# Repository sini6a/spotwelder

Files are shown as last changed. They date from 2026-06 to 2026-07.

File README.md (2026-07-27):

# Open Source Spot Welder

An easy-to-assemble, through-hole spot welder capable of switching high currents for welding nickel strip to lithium-ion cells. Controlled by an ATtiny13 microcontroller.

The welder is powered by a 12 V car battery or another suitable high-current battery source. The PCB, schematic, firmware, enclosure, and fabrication files are included in this repository.

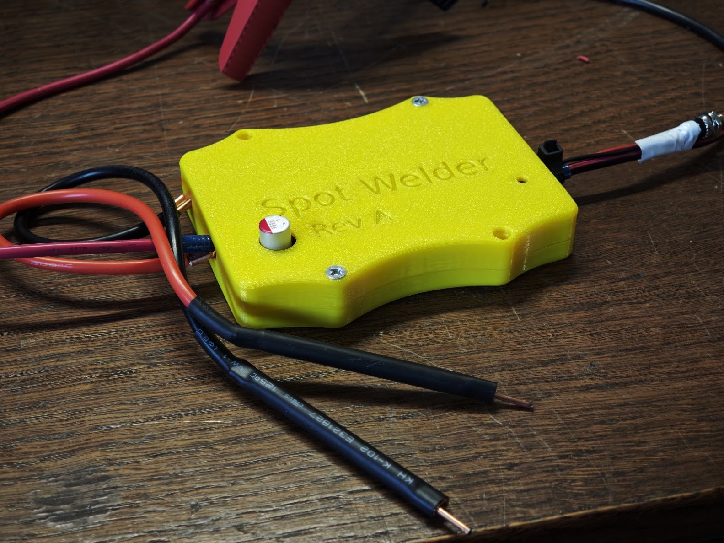
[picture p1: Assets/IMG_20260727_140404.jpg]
Board Assembly

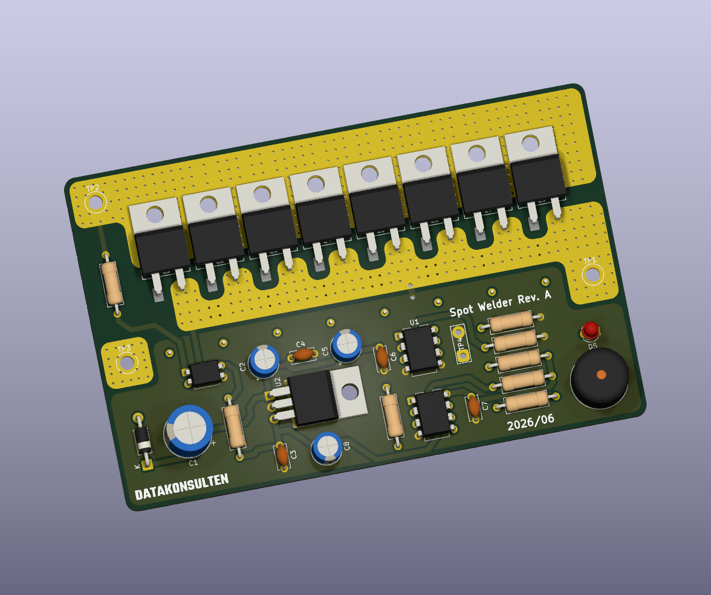
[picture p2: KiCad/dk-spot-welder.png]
Board render


> [!WARNING]
> This project switches extremely high current from a battery. Incorrect wiring, insufficient conductors, short circuits, or excessive pulse duration can cause fire, burns, damaged cells, destroyed MOSFETs, or battery failure.

## Sponsor

PCB fabrication for this project was sponsored by [PCBWay](https://www.pcbway.com/).

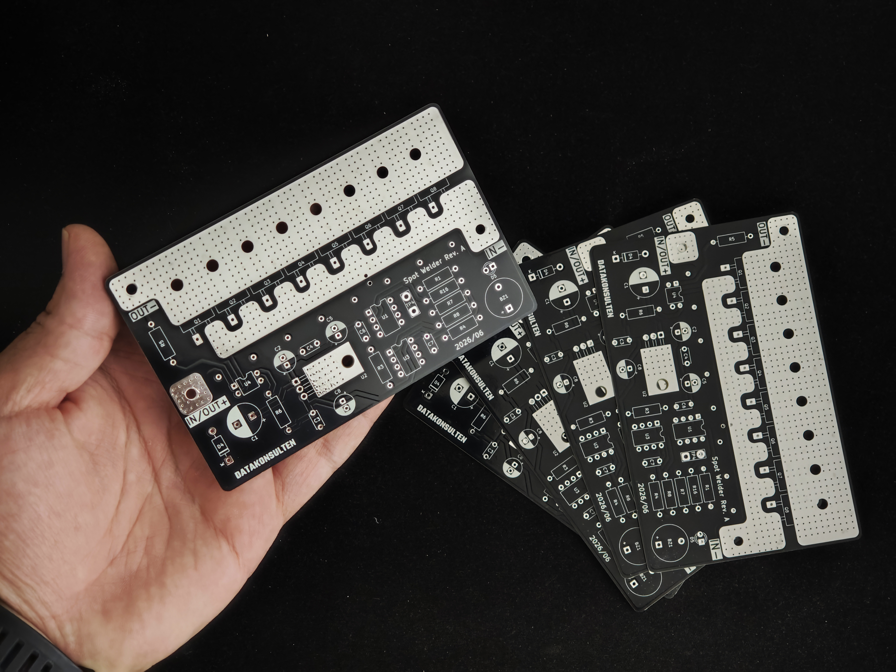
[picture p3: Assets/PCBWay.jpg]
PCBWay PCBs


## Features

* **Eight-MOSFET switching bank**
  Eight IRF1404 N-channel MOSFETs are connected in parallel to switch the welding current. Each MOSFET has an individual 10 Ω gate resistor to help control switching and reduce gate ringing.

* **Dedicated MOSFET gate driver**
  An MCP1407 drives all eight MOSFET gates simultaneously. A hardware pull-down resistor on the driver input keeps the MOSFET bank off while the microcontroller is starting, resetting, or unpowered.

* **Automatic touch-to-weld triggering**
  A PC817 optocoupler-based sensing circuit detects when both welding probes are in contact with a conductive workpiece. The isolated output signals the ATtiny13 to begin the welding sequence.

* **Adjustable 1–10 ms main pulse**
  A pushbutton connected to TP4 cycles the main weld-pulse duration from 1 to 10 ms.

* **EEPROM setting storage**
  The selected weld duration is saved in the ATtiny13 EEPROM and restored after the welder is disconnected from power.

* **LED and buzzer feedback**
  The onboard LED and passive piezo buzzer provide startup, welding, and setting-change feedback. When the duration is changed, the LED flashes and the buzzer beeps once for each selected millisecond.

* **Optional double-pulse welding**
  The firmware can produce a short pre-pulse followed by the adjustable main pulse. The pre-pulse can help settle the probe contact before the main weld.

* **Separated control and power grounds**
  The high-current welding ground (`GND`) and logic ground (`CTRL_GND`) are routed separately and joined at a single net-tie point to reduce switching noise at the microcontroller.

* **Reverse-polarity protection**
  A 1N5819 Schottky diode protects the 5 V control supply if the battery input is accidentally connected with reversed polarity.

* **Transient suppression**
  Four 5.0SMDJ14A TVS diodes help clamp voltage transients generated by the welding cables and other parasitic inductance when the MOSFET bank switches off.

* **Large high-current connection pads**
  The battery and welding connections use large exposed copper pads intended for soldered or mechanically secured high-current conductors.

* **Four-layer PCB**
  Copper zones on F.Cu, In1.Cu, In2.Cu, and B.Cu help distribute the short welding-current pulses through the MOSFET bank.

> [!IMPORTANT]
> PCB copper alone should not be treated as a complete high-current busbar. Thick copper cable, copper braid, copper strip, or another suitable reinforcement is recommended for the main battery and electrode current paths.

## How it works

1. **Power input**
   A 12 V car battery or another suitable high-current battery source is connected to the `IN/OUT+` and `IN-` pads.

2. **Probe contact detection**
   When both welding probes contact the conductive workpiece, the PC817 sensing circuit produces an isolated trigger signal for the ATtiny13.

3. **Trigger validation**
   The firmware verifies that the contact signal remains active for the configured debounce period.

4. **Pre-pulse**
   When double-pulse mode is enabled, the ATtiny13 briefly activates the MCP1407 and MOSFET bank for the configured pre-pulse duration.

5. **Pulse gap**
   The MOSFETs switch off for a short interval before the main pulse.

6. **Main weld pulse**
   The MOSFET bank switches on for the selected duration between 1 and 10 ms, passing a short burst of high current through the nickel strip and cell connection.

7. **Feedback and cooldown**
   The buzzer and LED confirm that the weld sequence completed. The firmware then enforces a cooldown period and waits for the probes to be lifted before another weld can begin.

## Weld-time adjustment

TP4 is used to change the main weld-pulse duration.

Each complete button press advances the setting by 1 ms:

```text
1 → 2 → 3 → 4 → 5 → 6 → 7 → 8 → 9 → 10 → 1 ms
```

After the value changes:

* The setting is saved to EEPROM.
* The LED flashes once per selected millisecond.
* The buzzer beeps at the same time as each flash.

For example, a 6 ms setting produces six LED flashes and six beeps.

The displayed value represents the **main pulse only**. When double-pulse mode is enabled, the fixed pre-pulse is added separately.

## Firmware

The firmware is located at:

```text
Firmware/main.c
```

It directly controls:

* The MCP1407 gate-driver input
* The PC817 automatic weld trigger
* The TP4 settings button
* The status LED
* The passive piezo buzzer
* EEPROM storage for the selected duration

The firmware forces the MOSFET-driver control pin low during startup. This works together with the hardware pull-down resistor on the MCP1407 input to reduce the risk of an unintended weld pulse during reset or power-up.

### Default configuration

| Definition | Default | Description |
| --- | ---: | --- |
| `WELD_PULSE_MIN_MS` | 1 ms | Lowest selectable main-pulse duration |
| `WELD_PULSE_MAX_MS` | 10 ms | Highest selectable main-pulse duration |
| `WELD_PULSE_DEFAULT_MS` | 6 ms | Used when EEPROM does not contain a valid setting |
| `USE_DOUBLE_PULSE` | 1 | Enables the pre-pulse and main-pulse sequence |
| `PRE_PULSE_MS` | 3 ms | Fixed pre-pulse duration |
| `PULSE_GAP_MS` | 80 ms | Delay between the pre-pulse and main pulse |
| `WELD_COOLDOWN_MS` |  800 ms | Minimum delay after a weld before re-arming |
| `TRIGGER_DEBOUNCE_MS` | 15 ms | Probe-contact validation time |
| `REQUIRE_TRIGGER_RELEASE` | 1 | Requires the probes to be lifted before another weld |
| `BEEP_ON_WELD_MS` | 60 ms | Weld-confirmation tone duration |
| `BUZZER_ACTIVE_TYPE` | 0 | Configures BZ1 as an externally driven passive piezo |
| `BUZZER_TONE_HZ` | 4000 Hz | Normal feedback-tone frequency |

Review the values in `Firmware/main.c` before flashing, as development versions may use different pre-pulse and timing defaults.

### Building and flashing

The firmware is built with AVR-GCC and optimized for the ATtiny13's limited 1 KB program memory.

```bash
cd Firmware

make
make flash
make fuses
```

The default Makefile targets are:

| Command | Action |
| --- | --- |
| `make` | Build the firmware and generate the HEX file |
| `make flash` | Flash the firmware over ISP |
| `make fuses` | Configure the 9.6 MHz internal oscillator with the divide-by-8 fuse, resulting in a 1.2 MHz CPU clock |

The default programmer configuration may need to be changed in the Makefile when using an Arduino as ISP instead of a USBasp.

## Enclosure

A two-piece enclosure is included and was designed in FreeCAD. 3xM4 Nuts should be installed while printing the enclosure.

| Assembled | Top and bottom |
| --- | --- |
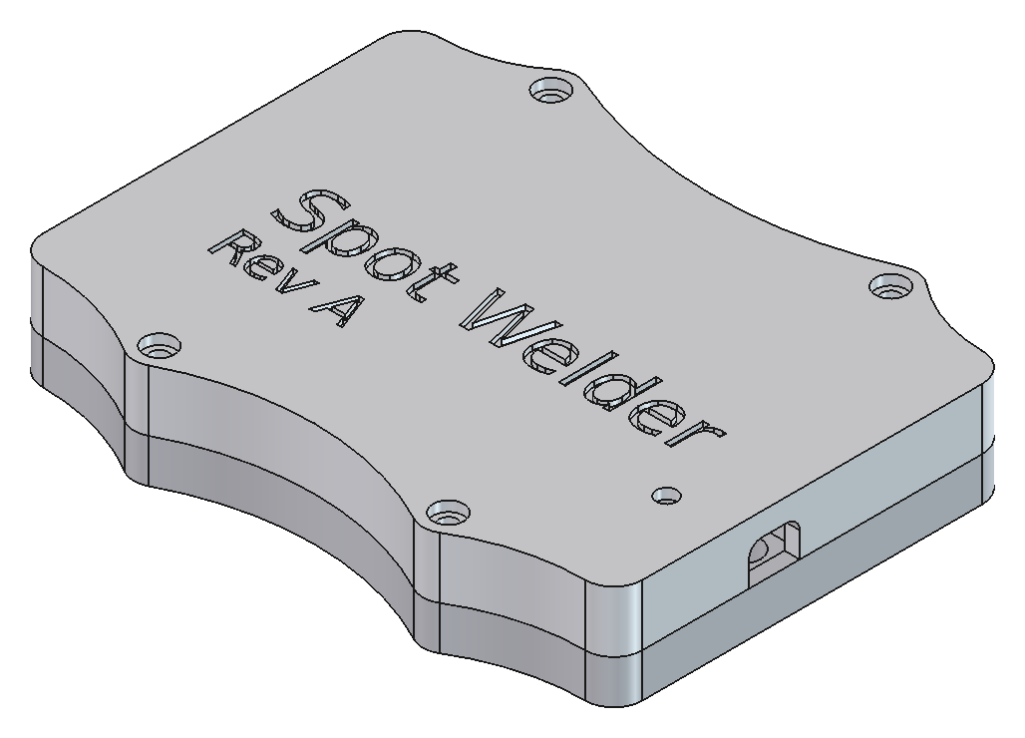
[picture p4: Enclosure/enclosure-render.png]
Enclosure render
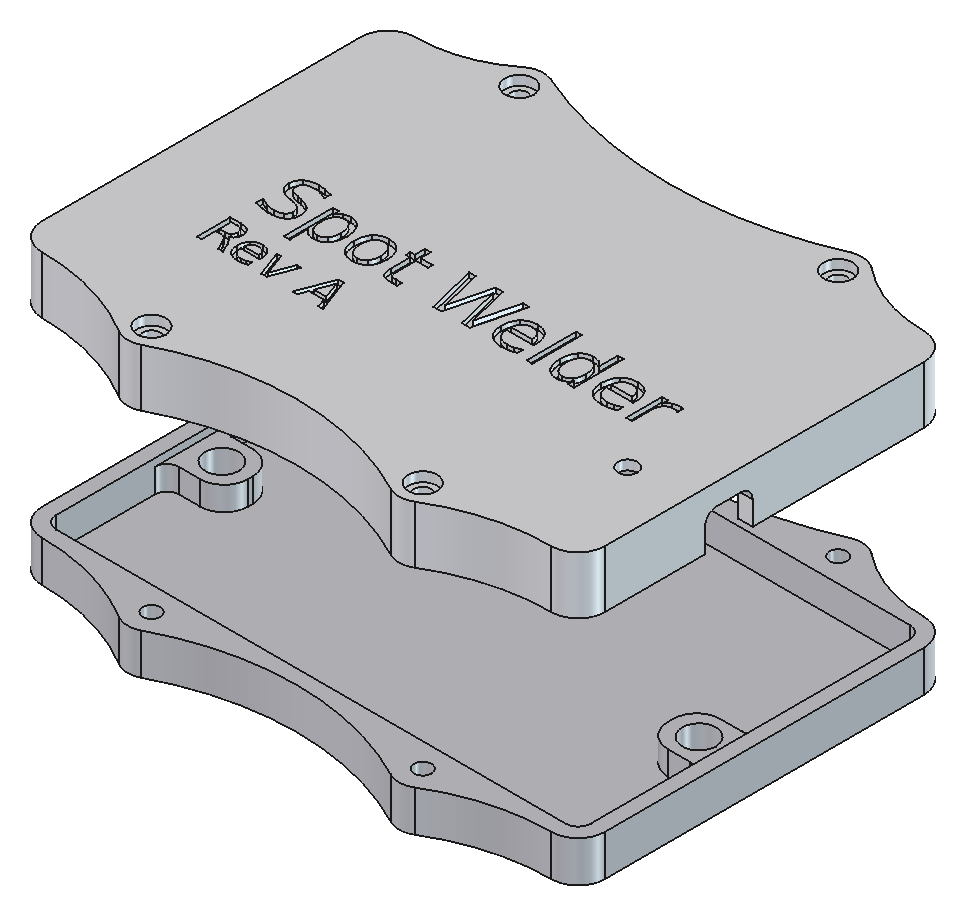
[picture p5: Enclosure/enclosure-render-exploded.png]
Exploded enclosure render
|  |  |

The enclosure includes:

* Four mounting bosses
* Screw-together top and bottom sections
* Side openings for the battery and electrode cables
* Source files for modification and 3D printing

Included files:

```text
Enclosure/SpotWelder.FCStd
Enclosure/Top Body.step
Enclosure/Bottom Body.step
```

## Project status

The Rev A hardware has been assembled, powered, and successfully used for spot welding.

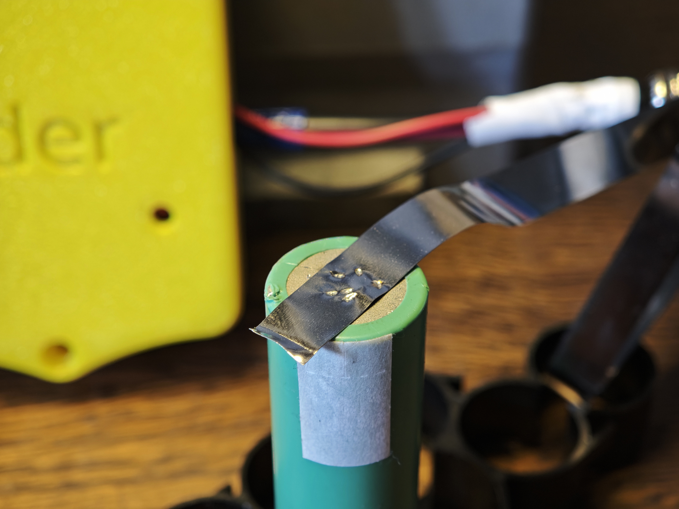
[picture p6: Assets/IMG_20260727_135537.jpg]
Battery weld


The following core functions have been tested:

* ATtiny13 startup
* MOSFET gate-driver control
* Automatic probe-contact triggering
* Timed welding pulses
* LED feedback
* Passive buzzer feedback
* Welding from a 12 V car battery

## License

This project is licensed under the **Creative Commons Attribution-NonCommercial-ShareAlike 4.0 International license**.

See [LICENCE.md](LICENCE.md) for the complete terms.

You may build, modify, and share the design for personal and non-commercial use, provided that attribution is retained and derivative works use the same license.

Commercial production or resale of boards based on this design requires permission from Datakonsulten Sverige AB.

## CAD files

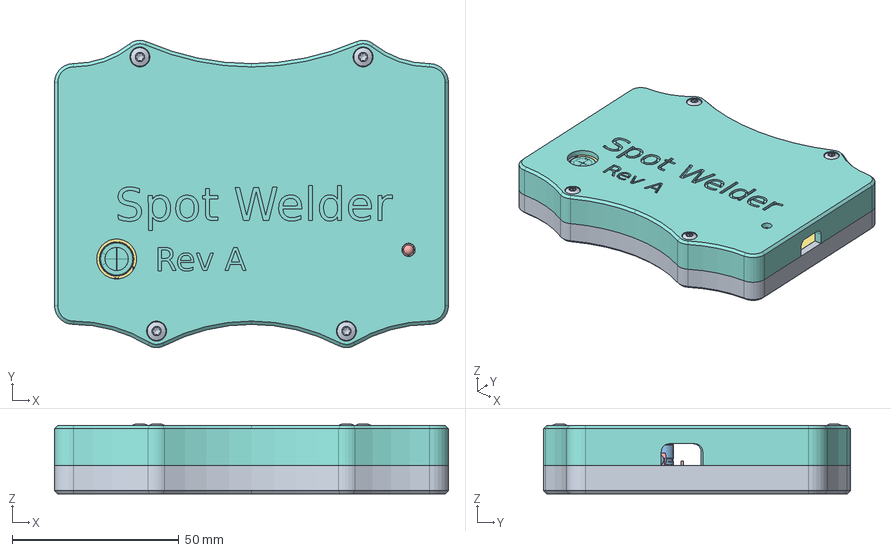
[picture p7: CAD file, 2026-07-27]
Enclosure/SpotWelder.FCStd
118.3 x 92.3 x 21.0 mm
Bottom Body
M4-Nut x 3
R_Axial_DIN0309_L90mm_D32mm_P1270mm_Horizontal
R_Axial_DIN0309_L90mm_D32mm_P1270mm_Horizontal001
LED_D3.0mm
C_Disc_D50mm_W25mm_P500mm
TO-220-2_Horizontal_TabDown
CP_Radial_D100mm_P500mm
TO-220-2_Horizontal_TabDown002
DIP-8_W7.62mm
CP_Radial_D63mm_P250mm
TO-220-2_Horizontal_TabDown004
TO-220-3_Horizontal_TabDown
TO-220-2_Horizontal_TabDown006
TO-220-2_Horizontal_TabDown008
TO-220-2_Horizontal_TabDown010
TO-220-2_Horizontal_TabDown012
CP_Radial_D63mm_P250mm001
R_Axial_DIN0309_L90mm_D32mm_P1270mm_Horizontal002
R_Axial_DIN0309_L90mm_D32mm_P1270mm_Horizontal003
Buzzer_12x95RM76
R_Axial_DIN0309_L90mm_D32mm_P1270mm_Horizontal004
C_Disc_D50mm_W25mm_P500mm001
R_Axial_DIN0309_L90mm_D32mm_P1270mm_Horizontal005
R_Axial_DIN0309_L90mm_D32mm_P1270mm_Horizontal006
C_Disc_D50mm_W25mm_P500mm002
C_Disc_D50mm_W25mm_P500mm003
D_DO-41_SOD81_P10.16mm_Horizontal
DIP-8_W7.62mm002
CP_Radial_D63mm_P250mm002
TO-220-2_Horizontal_TabDown014
DIP-4_W7.62mm
R_Axial_DIN0309_L90mm_D32mm_P1270mm_Horizontal007
D_SMC
R_Axial_DIN0309_L90mm_D32mm_P1270mm_Horizontal008
D_SMC002
R_Axial_DIN0309_L90mm_D32mm_P1270mm_Horizontal009
R_Axial_DIN0309_L90mm_D32mm_P1270mm_Horizontal010
R_Axial_DIN0309_L90mm_D32mm_P1270mm_Horizontal011
R_Axial_DIN0309_L90mm_D32mm_P1270mm_Horizontal012
R_Axial_DIN0309_L90mm_D32mm_P1270mm_Horizontal013
D_SMC004
R_Axial_DIN0309_L90mm_D32mm_P1270mm_Horizontal014
D_SMC006
R_Axial_DIN0309_L90mm_D32mm_P1270mm_Horizontal015
dk-spot-welder_silkscreen
dk-spot-welder_silkscreen001
dk-spot-welder_silkscreen002
dk-spot-welder_silkscreen003
dk-spot-welder_silkscreen004
dk-spot-welder_silkscreen005
dk-spot-welder_silkscreen006
dk-spot-welder_silkscreen007
dk-spot-welder_silkscreen008
dk-spot-welder_silkscreen009
dk-spot-welder_silkscreen010
dk-spot-welder_silkscreen011
dk-spot-welder_silkscreen012
dk-spot-welder_silkscreen013
dk-spot-welder_silkscreen014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

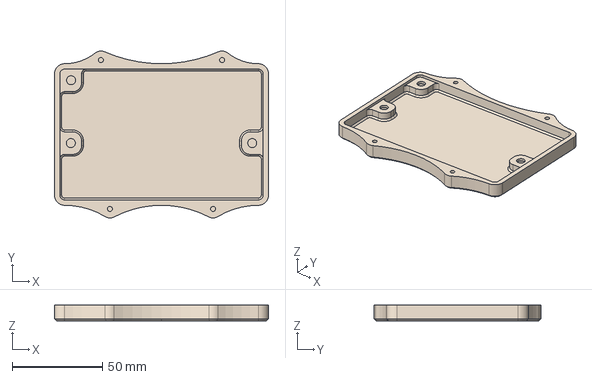
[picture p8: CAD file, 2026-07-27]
Enclosure/Bottom Body.step
118.3 x 92.3 x 8.60 mm

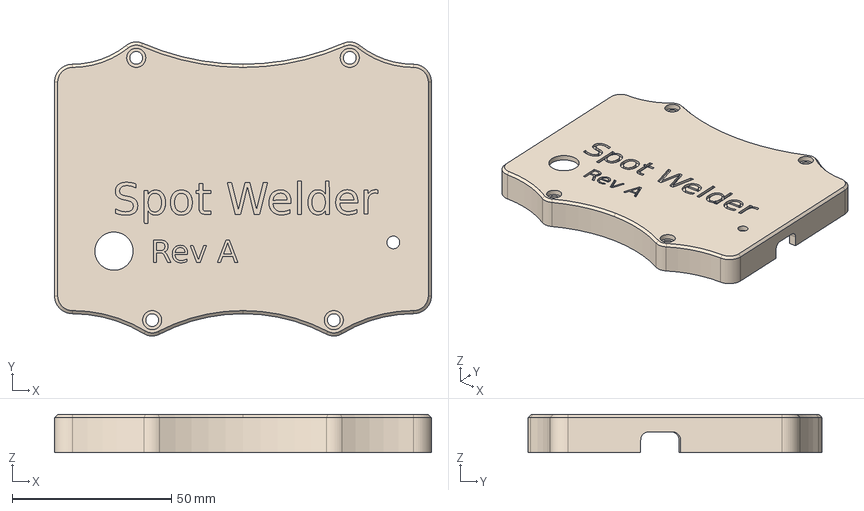
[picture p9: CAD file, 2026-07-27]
Enclosure/Top Body.step
118.3 x 92.3 x 12.0 mm

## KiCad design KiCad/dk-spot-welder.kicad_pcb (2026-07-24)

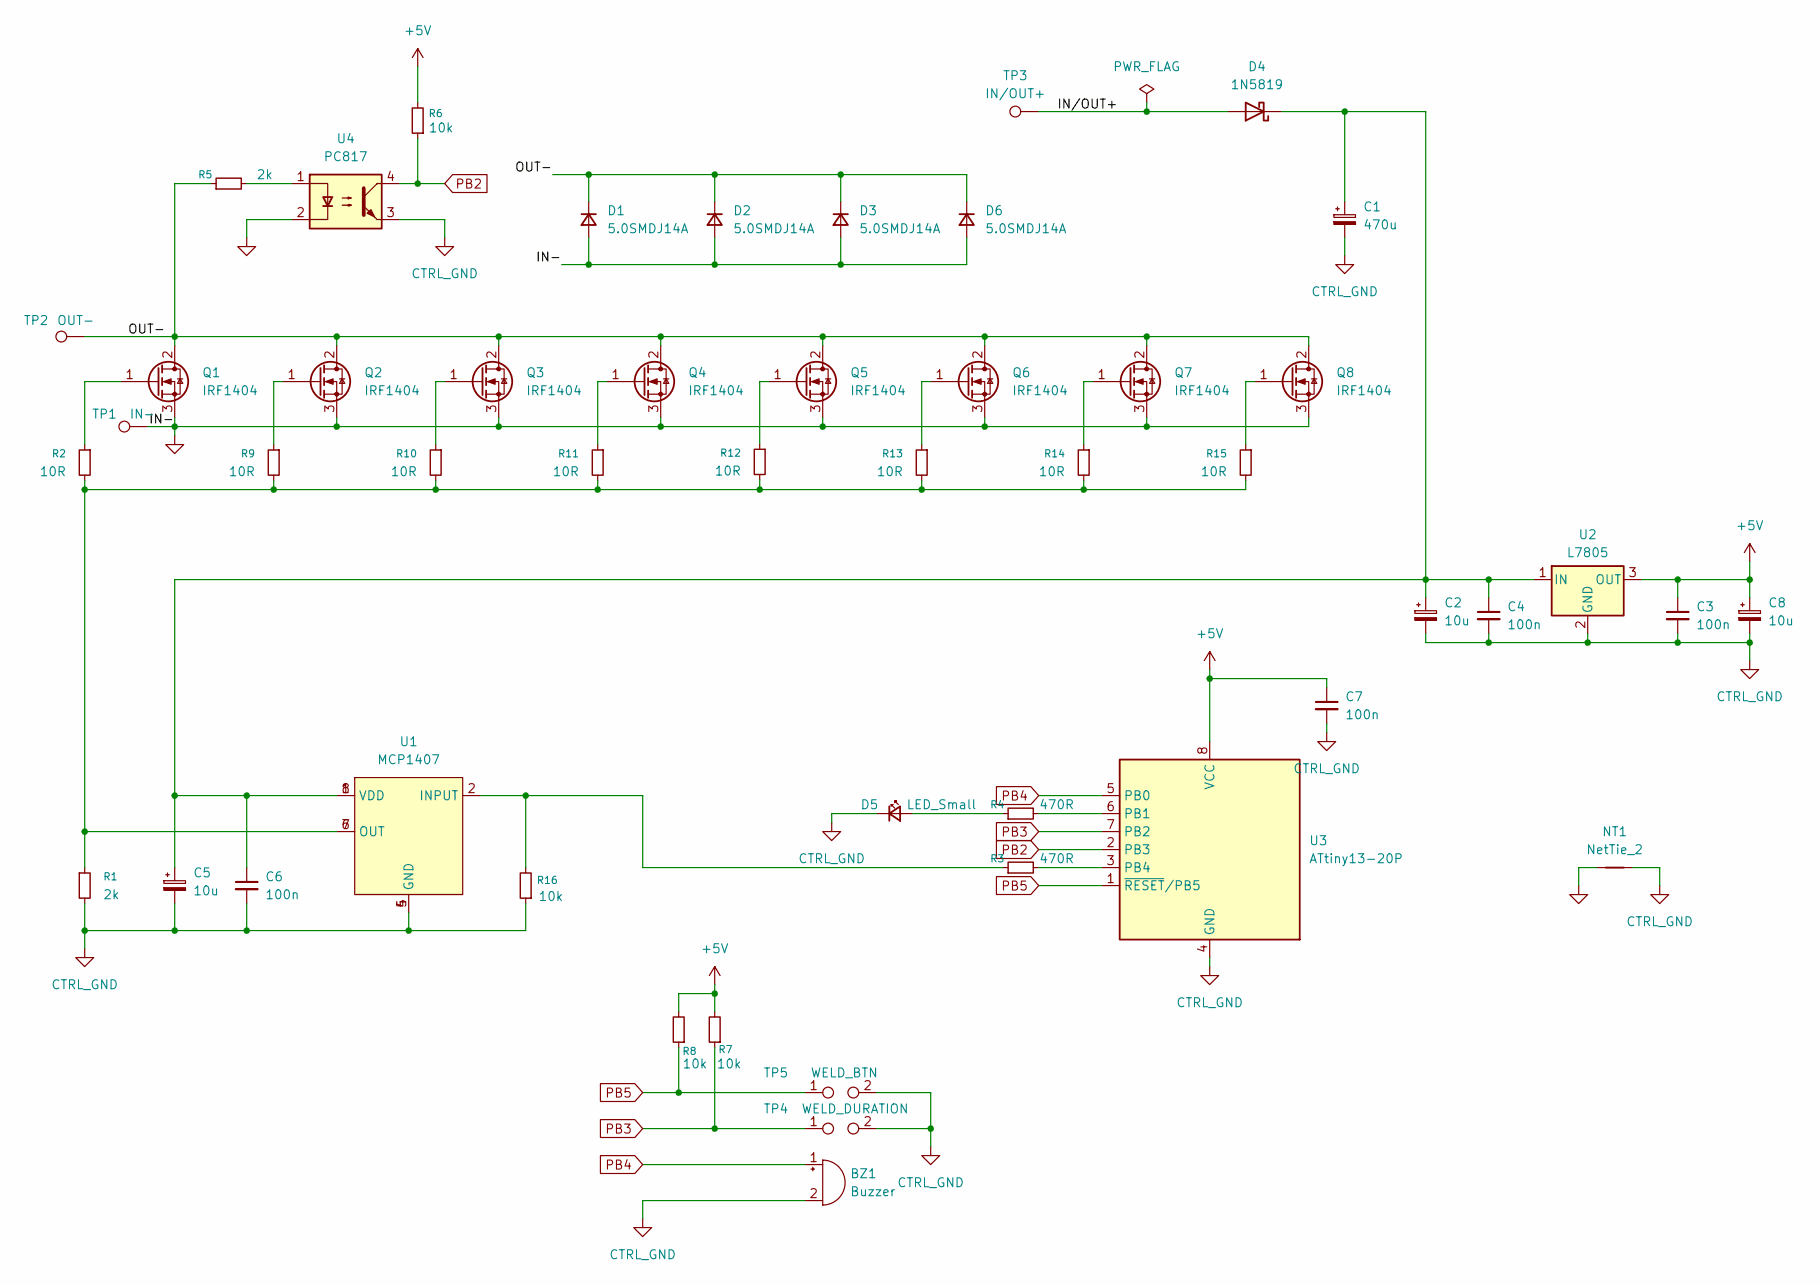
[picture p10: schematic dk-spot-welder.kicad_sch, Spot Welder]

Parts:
BZ1: Buzzer; Buzzer_12x9.5RM7.6
C1: 470u; CP_Radial_D10.0mm_P5.00mm
C2, C5, C8: 10u; CP_Radial_D6.3mm_P2.50mm
C3, C4, C6, C7: 100n; C_Disc_D5.0mm_W2.5mm_P5.00mm
D1, D2, D3, D6: 5.0SMDJ14A; D_SMC_Handsoldering
D4: 1N5819; D_DO-41_SOD81_P10.16mm_Horizontal
D5: LED_Small; LED_D3.0mm
NT1: NetTie_2; NetTie-2_THT_Pad1.0mm
Q1, Q2, Q3, Q4, Q5, Q6, Q7, Q8: IRF1404; TO-220-2_Horizontal_TabDown
R1, R5: 2k; R_Axial_DIN0309_L9.0mm_D3.2mm_P12.70mm_Horizontal
R2, R9, R10, R11, R12, R13, R14, R15: 10R; R_Axial_DIN0309_L9.0mm_D3.2mm_P12.70mm_Horizontal
R3, R4: 470R; R_Axial_DIN0309_L9.0mm_D3.2mm_P12.70mm_Horizontal
R6, R7, R8, R16: 10k; R_Axial_DIN0309_L9.0mm_D3.2mm_P12.70mm_Horizontal
TP1: IN-; MountingHole_4mm_Pad_Via
TP2: OUT-; MountingHole_4mm_Pad_Via
TP3: IN/OUT+; MountingHole_4mm_Pad_Via
TP4: WELD_DURATION; TestPoint_2Pads_Pitch5.08mm_Drill1.3mm
TP5: WELD_BTN; TestPoint_2Pads_Pitch5.08mm_Drill1.3mm
U1: MCP1407; DIP-8_W7.62mm
U2: L7805; TO-220-3_Horizontal_TabDown
U3: ATtiny13-20P; DIP-8_W7.62mm
U4: PC817; DIP-4_W7.62mm

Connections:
+5V: C3.1, C7.1, C8.1, R6.2, R7.2, R8.2, U2.3 (OUT), U3.8 (VCC)
/IN/OUT+: D4.2 (A), TP3.1 (1_1)
/OUT-: D1.1 (K), D2.1 (K), D3.1 (K), D6.1 (K), Q1.2 (D), Q2.2 (D), Q3.2 (D), Q4.2 (D), Q5.2 (D), Q6.2 (D), Q7.2 (D), Q8.2 (D), R5.1, TP2.1 (1_1)
CTRL_GND: BZ1.2 (-), C1.2, C2.2, C3.2, C4.2, C5.2, C6.2, C7.2, C8.2, D5.1 (K), NT1.2, R1.2, R16.1, TP4.2, TP5.2, U1.4 (GND), U1.5 (GND), U2.2 (GND), U3.4 (GND), U4.3
GND: D1.2 (A), D2.2 (A), D3.2 (A), D6.2 (A), NT1.1, Q1.3 (S), Q2.3 (S), Q3.3 (S), Q4.3 (S), Q5.3 (S), Q6.3 (S), Q7.3 (S), Q8.3 (S), TP1.1 (1_1), U4.2
unnamed: C1.1, C2.1, C4.1, C5.1, C6.1, D4.1 (K), U1.1 (VDD), U1.8 (VDD), U2.1 (IN)
unnamed: D5.2 (A), R4.1
unnamed: Q1.1 (G), R2.1
unnamed: Q2.1 (G), R9.1
unnamed: Q3.1 (G), R10.1
unnamed: Q4.1 (G), R11.1
unnamed: Q5.1 (G), R12.1
unnamed: Q6.1 (G), R13.1
unnamed: Q7.1 (G), R14.1
unnamed: Q8.1 (G), R15.1
unnamed: R1.1, R2.2, R9.2, R10.2, R11.2, R12.2, R13.2, R14.2, R15.2, U1.6 (OUT), U1.7 (OUT)
unnamed: R5.2, U4.1
unnamed: R3.1, R16.2, U1.2 (INPUT)
unnamed: R4.2, U3.6 (PB1)
unnamed: R3.2, U3.3 (PB4)
PB2: R6.1, U3.2 (PB3), U4.4
PB3: R7.1, TP4.1, U3.7 (PB2)
PB4: BZ1.1 (+), U3.5 (PB0)
PB5: R8.1, TP5.1, U3.1 (~RESET/PB5)

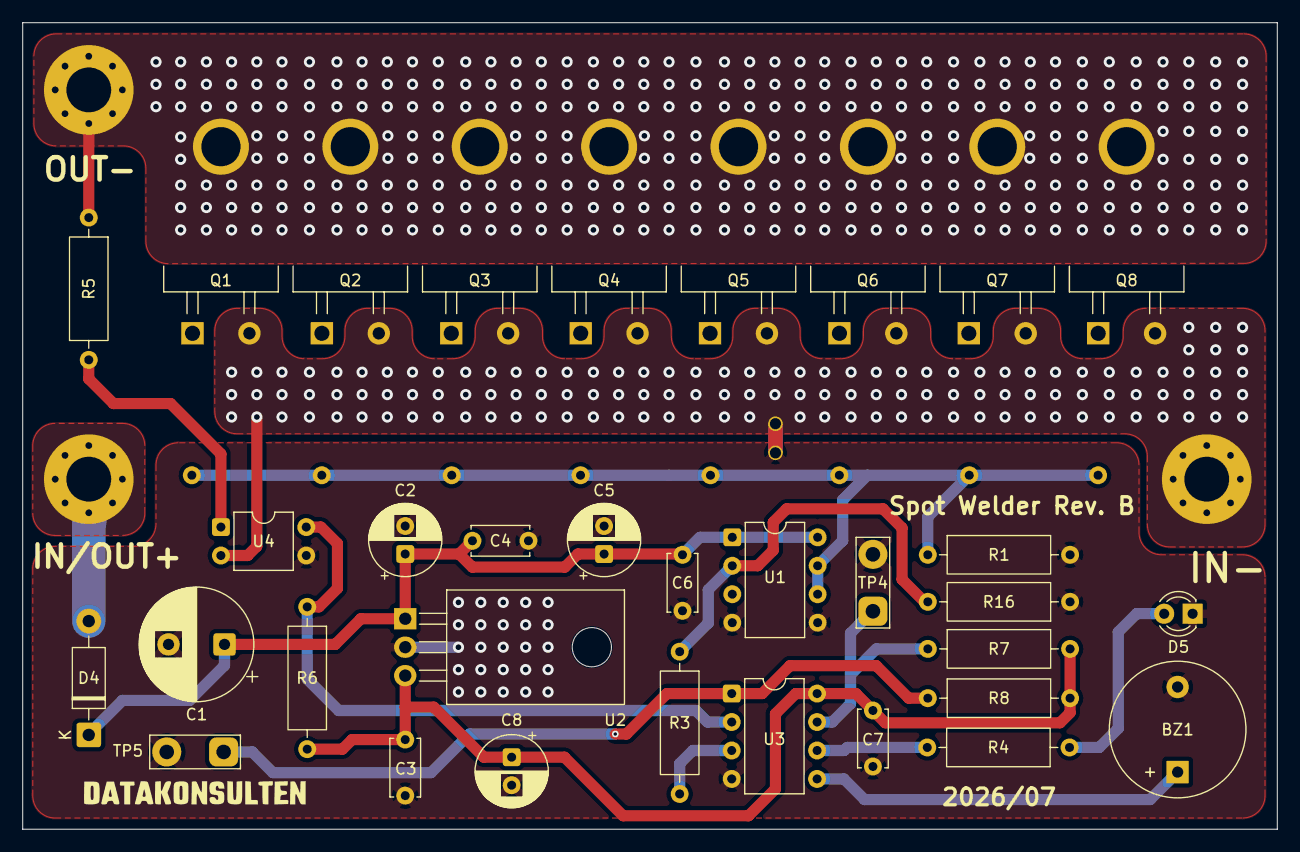
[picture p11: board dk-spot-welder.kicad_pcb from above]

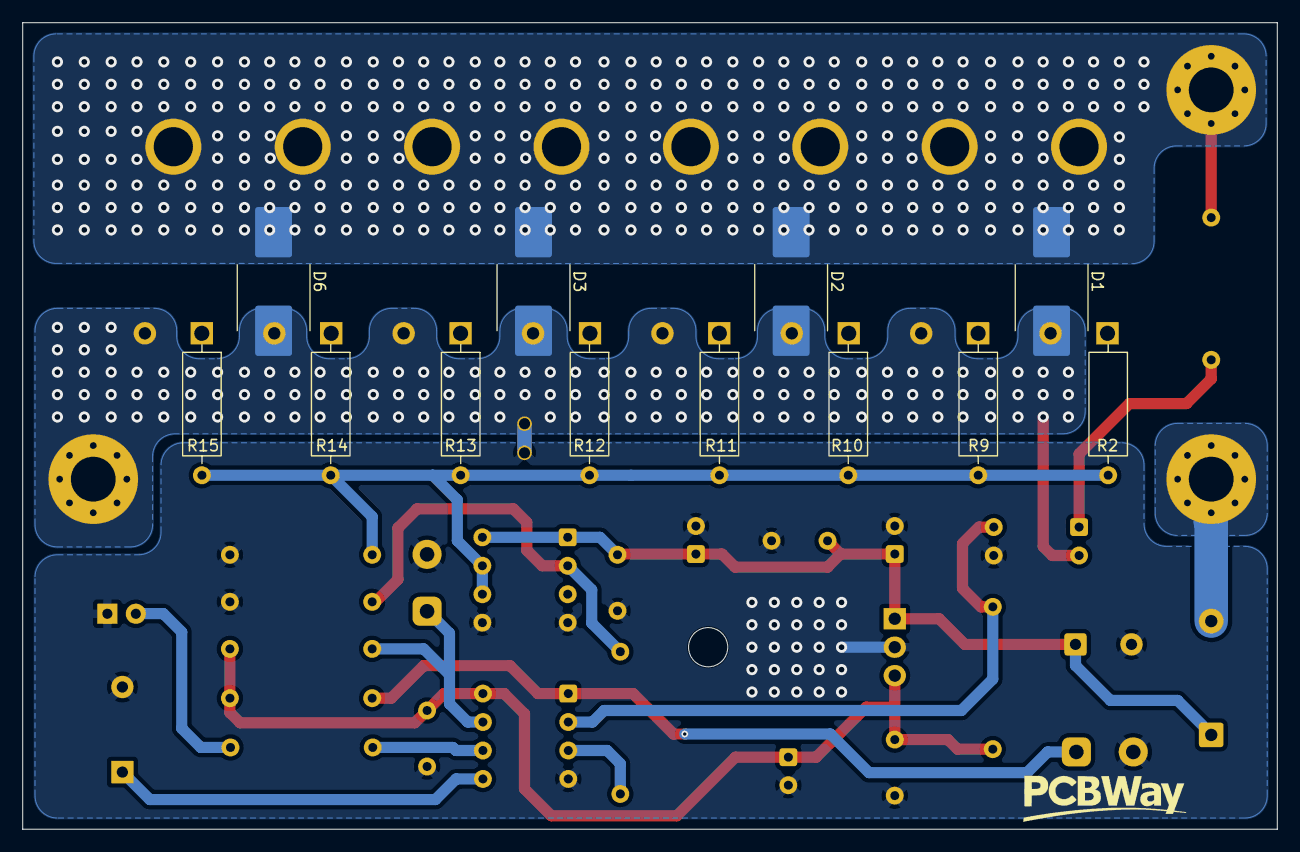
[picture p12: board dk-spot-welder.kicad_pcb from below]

Board: 4 copper layers, 112.0 x 72.0 mm, 49 parts (12 on the bottom side), 24 nets.

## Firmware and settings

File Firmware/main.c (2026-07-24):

/*
 * Datakonsulten Spot Welder - ATtiny13-20P firmware
 *
 * Pin mapping (derived from KiCad/dk-spot-welder.kicad_sch, U3):
 *   PB0 (pin 5) -> BZ1   buzzer, active HIGH, no series resistor (active/self-oscillating
 *                  piezo buzzer assumed - see BUZZER_ACTIVE_TYPE below)
 *   PB1 (pin 6) -> D5    status LED via R4, active HIGH
 *   PB2 (pin 7) -> TP4   manual trigger button header, external pull-up R7 to +5V,
 *                  active LOW (button pulls to CTRL_GND when pressed)
 *   PB3 (pin 2) -> U4    PC817 phototransistor output, external pull-up R6 to +5V,
 *                  active LOW (opto conducts when welding tips touch the workpiece)
 *   PB4 (pin 3) -> R3 -> U1 MCP1407 INPUT, active HIGH = MOSFET bank ON (welding current
 *                  flowing). R16 hardware-pulls this net low at the driver input as a
 *                  fail-safe, but firmware also forces PB4 low before anything else runs.
 *   PB5 (pin 1) -> RESET, pulled up by R8. Not used as GPIO.
 *
 * All user-tunable parameters are grouped at the top of this file.
 */

#define F_CPU 1200000UL   /* ATtiny13 factory-default fuses = 9.6MHz internal RC / 8 = 1.2MHz.
                              Must match the fuses actually programmed into the chip - see
                              Makefile `fuses` / `fuses-fast` targets. */

#include <avr/io.h>
#include <avr/eeprom.h>
#include <util/delay.h>

/* ===================== USER CONFIGURATION ===================== */

/* --- Weld pulse timing (milliseconds) --- */
#define WELD_PULSE_MIN_MS       1   /* Lowest selectable main-pulse duration */
#define WELD_PULSE_MAX_MS      10   /* Highest selectable main-pulse duration */
#define WELD_PULSE_DEFAULT_MS  5   /* Used when EEPROM contains an invalid value */

#define SETTINGS_BUTTON_MS      30   /* TP4 press and release debounce time */
#define SETTING_BLINK_ON_MS     80   /* LED-on time for each indication blink */
#define SETTING_BLINK_OFF_MS   120   /* LED-off time between indication blinks */
#define USE_DOUBLE_PULSE         1   /* 1 = fire a short pre-pulse before the main pulse,
                                         0 = single pulse only */
#define PRE_PULSE_MS              1   /* Pre-pulse duration (seats/cleans the tips on the
                                         workpiece before the main weld). Only used if
                                         USE_DOUBLE_PULSE == 1 */
#define PULSE_GAP_MS              50   /* Gap between pre-pulse and main pulse */

/* --- Safety / re-trigger protection --- */
#define WELD_COOLDOWN_MS        800   /* Minimum time after a weld fires before another can
                                         start, even if the trigger is still active */
#define TRIGGER_DEBOUNCE_MS      15   /* Stability time required for the PC817 weld trigger */
#define REQUIRE_TRIGGER_RELEASE   1   /* 1 = trigger (tip contact) must go inactive
                                         before the welder re-arms; strongly recommended -
                                         prevents continuous arcing/welding while the tips
                                         are left resting on the workpiece. 0 = re-arm
                                         immediately after cooldown. */

/* --- Feedback --- */
#define BEEP_ON_WELD_MS           60   /* Buzzer beep length right after a weld pulse fires */
#define LED_BLINK_POWERUP_MS     150   /* Startup LED blink length */
#define BUZZER_ACTIVE_TYPE         0   /* 1 = self-oscillating "active" buzzer - just needs
                                         DC applied (matches BZ1 being wired directly to the
                                         GPIO with no series resistor/transistor).
                                         0 = passive piezo - GPIO square-wave drive at
                                         BUZZER_TONE_HZ is generated instead. */
#define BUZZER_TONE_HZ           4000   /* Tone frequency used only if BUZZER_ACTIVE_TYPE == 0 */
/*
 * Timer0 uses a divide-by-8 clock.
 *
 * Output frequency:
 * F_CPU / (2 × 8 × (OCR0A + 1))
 *
 * The calculation is done at compile time, so it does not consume
 * runtime flash code for division.
 */
#define TONE_OCR(frequency) \
    ((uint8_t)(((F_CPU + (8UL * (frequency))) / (16UL * (frequency))) - 1UL))

/* Hard ceiling - refuses to compile an accidentally dangerous pulse length.
   Raise only if you really know what you are doing. */
#if USE_DOUBLE_PULSE
    #if (WELD_PULSE_MAX_MS + PRE_PULSE_MS) > 500
        #error "Maximum combined weld pulse exceeds the 500ms safety ceiling"
    #endif
#else
    #if WELD_PULSE_MAX_MS > 500
        #error "Maximum weld pulse exceeds the 500ms safety ceiling"
    #endif
#endif

/* ================================================================= */

/* --- Pin assignments (see header comment for derivation) --- */
#define PIN_BUZZER  PB0
#define PIN_LED     PB1
#define PIN_BTN     PB2   /* TP4 weld-duration settings button, active LOW */
#define PIN_OPTO    PB3   /* automatic tip-touch trigger, via U4/PC817 */
#define PIN_WELD    PB4   /* MOSFET bank enable, via U1/MCP1407 */

/* Millisecond delay built from a compile-time-constant _delay_us() call per iteration,
   rather than a single runtime _delay_ms() call, to keep code size small on the
   ATtiny13's 1KB flash. */
static void delay_ms(uint16_t ms)
{
    while (ms--) {
        _delay_us(1000);
    }
}

static uint8_t EEMEM eeprom_weld_pulse_ms;
static uint8_t weld_pulse_ms;

static inline void weld_on(void)  { PORTB |=  (1 << PIN_WELD); }
static inline void weld_off(void) { PORTB &= ~(1 << PIN_WELD); }
static inline void led_on(void)   { PORTB |=  (1 << PIN_LED); }
static inline void led_off(void)  { PORTB &= ~(1 << PIN_LED); }
static inline void buzzer_on(void)  { PORTB |=  (1 << PIN_BUZZER); }
static inline void buzzer_off(void) { PORTB &= ~(1 << PIN_BUZZER); }

static void load_weld_setting(void)
{
    uint8_t saved_value = eeprom_read_byte(&eeprom_weld_pulse_ms);

    if ((saved_value < WELD_PULSE_MIN_MS) ||
        (saved_value > WELD_PULSE_MAX_MS)) {
        weld_pulse_ms = WELD_PULSE_DEFAULT_MS;
    } else {
        weld_pulse_ms = saved_value;
    }
}

/*
 * Play a tone using Timer0 and the OC0A hardware output on PB0.
 *
 * PB0 is OC0A on the ATtiny13. Timer0 toggles the pin automatically,
 * so the CPU only has to wait for the requested duration.
 */
static void passive_tone(uint8_t timer_value, uint16_t duration_ms)
{
    /* Make sure the buzzer begins LOW. */
    buzzer_off();

    /* Stop and reset Timer0 before configuring it. */
    TCCR0A = 0;
    TCCR0B = 0;
    TCNT0 = 0;

    /* Set the requested frequency. */
    OCR0A = timer_value;

    /*
     * CTC mode:
     * WGM01 = 1
     *
     * Toggle OC0A/PB0 each time the timer reaches OCR0A:
     * COM0A0 = 1
     */
    TCCR0A = (1 << COM0A0) | (1 << WGM01);

    /*
     * Start Timer0 with clock divided by 8:
     * CS01 = 1
     */
    TCCR0B = (1 << CS01);

    delay_ms(duration_ms);

    /* Stop Timer0. */
    TCCR0B = 0;

    /* Disconnect Timer0 from PB0. */
    TCCR0A = 0;

    /* Guarantee that the buzzer finishes LOW. */
    buzzer_off();
}

static void beep(uint16_t ms)
{
#if BUZZER_ACTIVE_TYPE
    buzzer_on();
    delay_ms(ms);
    buzzer_off();
#else
    passive_tone(TONE_OCR(BUZZER_TONE_HZ), ms);
#endif
}

static void welcome_chirp(void)
{
#if BUZZER_ACTIVE_TYPE
    /*
     * An active buzzer cannot change pitch, so use two short beeps.
     */
    beep(60);
    delay_ms(40);
    beep(100);
#else
    /*
     * Rising three-note startup chirp:
     *
     * Approximately 2 kHz → 3 kHz → 4 kHz
     */

    passive_tone(TONE_OCR(2000UL), 45);
    delay_ms(20);

    passive_tone(TONE_OCR(3000UL), 45);
    delay_ms(20);

    passive_tone(TONE_OCR(4000UL), 100);
#endif
}

static inline uint8_t weld_trigger_active(void)
{
    return ((PINB & (1 << PIN_OPTO)) == 0); /* PC817 triggers welding */
}

static inline uint8_t settings_button_active(void)
{
    return ((PINB & (1 << PIN_BTN)) == 0);  /* TP4 changes weld duration */
}

static void show_weld_setting(void)
{
    uint8_t blinks = weld_pulse_ms;

    while (blinks--) {
        led_on();
        beep(SETTING_BLINK_ON_MS);

        led_off();
        delay_ms(SETTING_BLINK_OFF_MS);
    }
}

static void handle_settings_button(void)
{
    delay_ms(SETTINGS_BUTTON_MS);

    if (!settings_button_active()) {
        return;                             /* Ignore a short noise pulse */
    }

    while (settings_button_active()) {
        /* Wait for TP4 to be released */
    }

    delay_ms(SETTINGS_BUTTON_MS);           /* Debounce the release */

    weld_pulse_ms++;

    if (weld_pulse_ms > WELD_PULSE_MAX_MS) {
        weld_pulse_ms = WELD_PULSE_MIN_MS;
    }

    eeprom_update_byte(&eeprom_weld_pulse_ms, weld_pulse_ms);

    show_weld_setting();
}

static void fire_weld(void)
{
#if USE_DOUBLE_PULSE
    if (weld_pulse_ms >= 3) {
        weld_on();
        delay_ms(PRE_PULSE_MS);
        weld_off();

        delay_ms(PULSE_GAP_MS);
    }
#endif

    weld_on();
    delay_ms(weld_pulse_ms);
    weld_off();

    beep(BEEP_ON_WELD_MS);

    led_on();
    delay_ms(60);
    led_off();
}

static void power_up_selftest(void)
{
    led_on();
    welcome_chirp();
    delay_ms(LED_BLINK_POWERUP_MS);
    led_off();
}

int main(void)
{
    /* Force the weld output low before touching anything else - this is the first thing
       that runs after reset, ahead of any other setup. R16 on the board does the same
       thing in hardware as a backstop. */
    PORTB &= ~(1 << PIN_WELD);
    DDRB |= (1 << PIN_WELD);
    
    /* Remaining outputs. */
    PORTB &= ~((1 << PIN_LED) | (1 << PIN_BUZZER));
    DDRB |= (1 << PIN_LED) | (1 << PIN_BUZZER);

    /* Trigger inputs, with internal pull-ups enabled alongside the external R6/R7
       pull-ups for extra noise immunity. */
    PORTB |= (1 << PIN_BTN) | (1 << PIN_OPTO);
    DDRB &= ~((1 << PIN_BTN) | (1 << PIN_OPTO));

    ADCSRA &= ~(1 << ADEN); /* ADC unused - save power */

    load_weld_setting();
    power_up_selftest();

for (;;) {
    if (settings_button_active()) {
        handle_settings_button();
        continue;
    }

    if (weld_trigger_active()) {
        delay_ms(TRIGGER_DEBOUNCE_MS);

        if (weld_trigger_active()) {
            fire_weld();
            delay_ms(WELD_COOLDOWN_MS);

#if REQUIRE_TRIGGER_RELEASE
            while (weld_trigger_active()) {
                /* Wait until the welding probes are lifted */
            }

            delay_ms(TRIGGER_DEBOUNCE_MS);
#endif
              }
        }
    }
}

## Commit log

2026-07-01 added assembly and fixed fixture
    [SpotWelder.FCStd]
2026-07-01 added PCBWay logo
    [dk-spot-welder.kicad_pcb]
2026-07-01 updated margins for 4 screws
    [SpotWelder.FCStd]
2026-07-01 add chamfer and hole for buzzer
    [SpotWelder.FCStd]
2026-07-01 update step files with latest updates
    [SpotWelder-Bottom Body.step, SpotWelder-Top Body w_ Text.step]
2026-07-01 change appearance
    [SpotWelder.FCStd]
2026-07-02 update connections from M3 to 4mm
    [dk-spot-welder.kicad_pcb, dk-spot-welder.kicad_sch]
2026-07-19 update from m3 to m4
    [SpotWelder-Bottom Body.step, SpotWelder.FCStd]
2026-07-19 update margin for m3 screws on top, fixed nut size opening on bottom
    [SpotWelder-Bottom Body.step, SpotWelder-Top Body w_ Text.step, SpotWelder.FCStd]
2026-07-24 updated firmware user selectable from 1 to 10ms weld duration + some improvements
2026-07-24 add another tp on PB5 to use with manual weld button
    [dk-spot-welder.kicad_pcb, dk-spot-welder.kicad_sch]
2026-07-24 added thermal relief for easier soldering
    [dk-spot-welder.kicad_pcb]
2026-07-24 changed to use through hole, and another diameter for connecting with resistor
2026-07-24 redesigned vias and exposed copper
    [dk-spot-welder.kicad_pcb]
2026-07-24 updated gerbers to rev. b
    [dk-spot-welder-B_Cu.gbr, dk-spot-welder-B_Mask.gbr, dk-spot-welder-B_Paste.gbr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]
2026-07-27 Cleanup readme and changed name of 3d step files
    [Bottom Body.step, Top Body.step]
2026-07-27 Added board image
2026-07-27 added capacitor hole
    [Bottom Body.step, SpotWelder.FCStd, Top Body.step]
2026-07-29 fixed gerbers to latest commit
    [dk-spot-welder-B_Cu.gbr, dk-spot-welder-B_Mask.gbr, dk-spot-welder-B_Paste.gbr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]
2026-07-29 add .zip in gitignore. always check gerbers before ordering
